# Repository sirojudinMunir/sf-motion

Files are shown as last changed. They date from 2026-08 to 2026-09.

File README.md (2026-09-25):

# SF-Motion

**Open-source BLDC/PMSM motor control platform based on STM32 and Field-Oriented Control (FOC).**

The project includes:

- FOC firmware
- Custom motor driver hardware
- KiCad schematic and PCB design
- Gerber and BOM files
- Python communication and control tools
- PyQt/PyQtGraph GUI for motor monitoring and testing

> ⚠️ This project is under active development. Hardware and firmware may change between versions.

## Hardware Prerequisites

You will need:
- FOC Driver Board
- ST-Link programmer/debugger with 3-pin Molex pico-blade P1.25mm connector
- DC power supply
- BLDC/PMSM motor
- diametrical magnet
- USB type-C cable
- power cable with XT-30 female connector

The hardware design is available in:
```
Hardware/
├── production/        # Gerber manufacturing files
├── .kicad_sch         # Schematic
├── .kicad_pcb         # PCB design
└── ...
```

## Software Prerequisites

### 1. STM32CubeMX

Used to configure the STM32 peripherals and generate the initial project configuration.

Download: https://www.st.com/en/development-tools/stm32cubemx.html

### 2. Visual Studio Code

Used as the main development environment.

Download: https://code.visualstudio.com/

### 3. PlatformIO

PlatformIO is used to build and upload the firmware.

Install PlatformIO through the VS Code extension:
1. Open VS Code.
2. Open Extensions.
3. Search for PlatformIO IDE.
4. Install the extension.
5. Restart VS Code if required.

Verify the installation:
``` bash
pio --version
```

If `pio` is not recognized in the terminal, use the PlatformIO terminal inside VS Code or add the PlatformIO CLI directory to your system PATH.

### 4. Python

Python is required for the communication tools and GUI.

Recommended version:
```text
Python 3.10+
```

Download: https://www.python.org/downloads/

Check the installation:
``` bash
python --version
```

Create a virtual environment (recommended):
``` bash
python -m venv .venv
```

Activate it on Windows:
``` bash
.venv\Scripts\activate
```

Activate it on Linux/macOS:
``` bash
source .venv/bin/activate
```

Install the required packages:
``` bash
pip install numpy pyserial PyQt5 pyqtgraph
```

## Getting Started

Clone the repository using Git:
``` bash
git clone https://github.com/sirojudinMunir/sf-motion.git
```

Enter the project directory:
``` bash
cd SF-Motion
```

## Building the Firmware

Open the project in VS Code with PlatformIO installed.

Build the firmware:
``` bash
pio run
```

If the build is successful, the firmware binary will be generated by PlatformIO.

## Upload Firmware

Connect the ST-Link to the FOC Driver board using the 3-pin PicoBlade connector.

The board can be powered from a **6–24 V external power supply**. For the initial test, it is recommended to use **USB Type-C** as the power source if applicable.

Upload the firmware:
``` bash
pio run -t upload
```

You can also use the Upload button in the PlatformIO interface in VS Code.

## For the first test

After uploading the firmware, follow these steps:

1. Make sure the D3 LED is blinking after the firmware starts.
2. Connect the BLDC/PMSM motor wires to the FOC Driver board. Make sure the diametrical magnet is securely mounted on the motor shaft and properly aligned with the magnetic encoder on the FOC Driver board. The board should be positioned directly beneath the magnet.
3. If you are using an external power supply, set the current limit to 1 A for the initial test. This helps prevent damage if there is an unexpected issue with the board or motor.
4. Connect the USB Type-C cable to the board.
5. Run the Python motor control program:
    ```python
    python communication/motor.py
    ```
6. Select the correct COM port and click Connect.

7. Before running the motor, set the correct motor pole pairs:
    ``` python
    motor.set_pole_pairs(<your_motor_pole_pairs>)
    ```
    Replace <your_motor_pole_pairs> with the actual number of pole pairs of your motor.
8. Run the self-commissioning process:
    ``` python
    motor.self_commissioning()
    ```
    The self-commissioning process measures the motor resistance and inductance and calibrates the magnetic encoder.
    >Important: During encoder calibration, make sure the motor rotates counter-clockwise (CCW). If the motor rotates in the opposite direction, swap any two motor wires to reverse the rotation.
    Automatic motor direction detection will be implemented in a future version.
9. Save configuration
    ``` python
    motor.set_save_config()
    ```
10. Test the FOC motor modes using:
    ``` python
    motor.set_motor_mode(<mode>)
    ```
    Available modes:

    0 -> for current control mode  
    1 -> for speed control mode  
    2 -> for position control mode  
    5 -> for open-loop mode  
    6 -> for disable the motor

> ⚠️ Keep the power supply current limit low during the first test. Do not increase the voltage or current limit until the board, encoder, and motor are confirmed to be working correctly.

---

## Support SF-Motion

If you find this project useful and would like to support its development,
you can become a sponsor:



Your support helps fund hardware development, testing, documentation,
and future improvements to SF-Motion.

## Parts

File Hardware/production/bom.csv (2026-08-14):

Designator | Footprint | Quantity | Value | LCSC Part #
C1, C10, C11, C2, C21, C3, C31, C37, C4, C40, C41, C45, C47, C48, C49, C5, C50, C51, C7 | 0402 | 19 | 100nF | C1525
C12, C16, C17, C25, C26, C27, C28, C29, C30, C32, C33, C34, C35, C38, C39, C43, C44 | 0805 | 17 | 10uF | C22367830
C13, C15 | 0603 | 2 | 0.1uF | C1591
C14 | 0805 | 1 | 4.7uF | C98192
C18, C20, C22 | 0603 | 3 | 1uF | C5199872
C19 | 0603 | 1 | 47nF | C1622
C23 | 0603 | 1 | 2.2uF | C23630
C24 | 0402 | 1 | 10nF | C15195
C36, C42, C46 | 0402 | 3 | 1nF | C14442
C6 | 0402 | 1 | 1uF | C29266
C8, C9 | 0402 | 2 | 33pF | C70465
D1, D2 | 0603 | 2 | LED RED | C19171390
D3 | 0603 | 1 | LED GREEN | C2986048
D4, D5 | D_SOD-123 | 2 | MBR0530 | C5204746
FB1 | 0603 | 1 | fcm 1608-0603 | C19330
J1, J8, J9 | Molex_PicoBlade_53261-0371_1x03-1MP_P1.25mm_Horizontal | 3 | Conn_01x03_MountingPin | C293630
J10 | Molex_PicoBlade_53261-0671_1x06-1MP_P1.25mm_Horizontal | 1 | Conn_01x06_MountingPin | C17393620
J11 | Molex_PicoBlade_53261-0571_1x05-1MP_P1.25mm_Horizontal | 1 | Conn_01x05_MountingPin | C17256390
J2, J3 | AMASS_XT30PW-M_1x02_P2.50mm_Horizontal | 2 | Conn_01x02 | C431092
J4, J5, J6 | SolderWire-0.25sqmm_1x01_D0.65mm_OD2mm | 3 | Conn_01x01
J7 | USB_C_Receptacle_G-Switch_GT-USB-7010ASV | 1 | USB_C_Receptacle_USB2.0_16P | C2927039
L1 | L_SMD_4X4 | 1 | 22uH | C6364792
Q1, Q2, Q3, Q4, Q5, Q6 | TDSON-8-1 | 6 | WSD30100DN56 | C2862136
R1, R3 | 0402 | 2 | 10k | C60490
R10, R11, R7, R8 | 0402 | 4 | R
R12, R15, R17, R21, R22, R25 | 0603 | 6 | 10R | C844919
R13, R19, R23 | R_Shunt_Ohmite_LVK20 | 3 | 0.01R | C844898
R14, R2, R20, R24, R32, R33, R34, R4, R5 | 0402 | 9 | 1k | C852624
R16 | 0603 | 1 | 39k | C163424
R18 | 0603 | 1 | 2k2 | C125931
R26 | 0402 | 1 | 1k8 | C163481
R27, R28 | 0402 | 2 | 100R | C705627
R29, R31 | 0402 | 2 | 30R | C852718
R30 | 0603 | 1 | 120R | C125925
R35, R36, R37 | 0402 | 3 | 2k | C852711
R6 | 0603 | 1 | 18k | C309650
R9 | 0603 | 1 | 3k3 | C144661
TP1, TP2, TP3, TP4, TP5, TP6, TP7 | TestPoint_Pad_D1.0mm | 7 | TestPoint
U1 | LQFP-64_10x10mm_P0.5mm | 1 | STM32F405RGTx | C15742
U10 | TSSOP-14_4.4x5mm_P0.65mm | 1 | AS5047D | C2693743
U2 | QFN50P700X700X100-49N | 1 | DRV8323RHRGZR | C543035
U3 | SOT-23-5 | 1 | LP2985-3.3 | C95414
U4, U6, U7 | TSSOP-8_4.4x3mm_P0.65mm | 3 | INA240A1PW | C93965
U5 | SOT-23-5 | 1 | LM321 | C5252901
U8 | SOT-23-6 | 1 | USBLC6-2SC6 | C2827654
U9 | HVSON-8-1EP_3x3mm_P0.65mm_EP1.6x2.4mm | 1 | TJA1051TK-3 | C2875699
Y1 | Crystal_SMD_3225-4Pin_3.2x2.5mm | 1 | 12MHz | C9002

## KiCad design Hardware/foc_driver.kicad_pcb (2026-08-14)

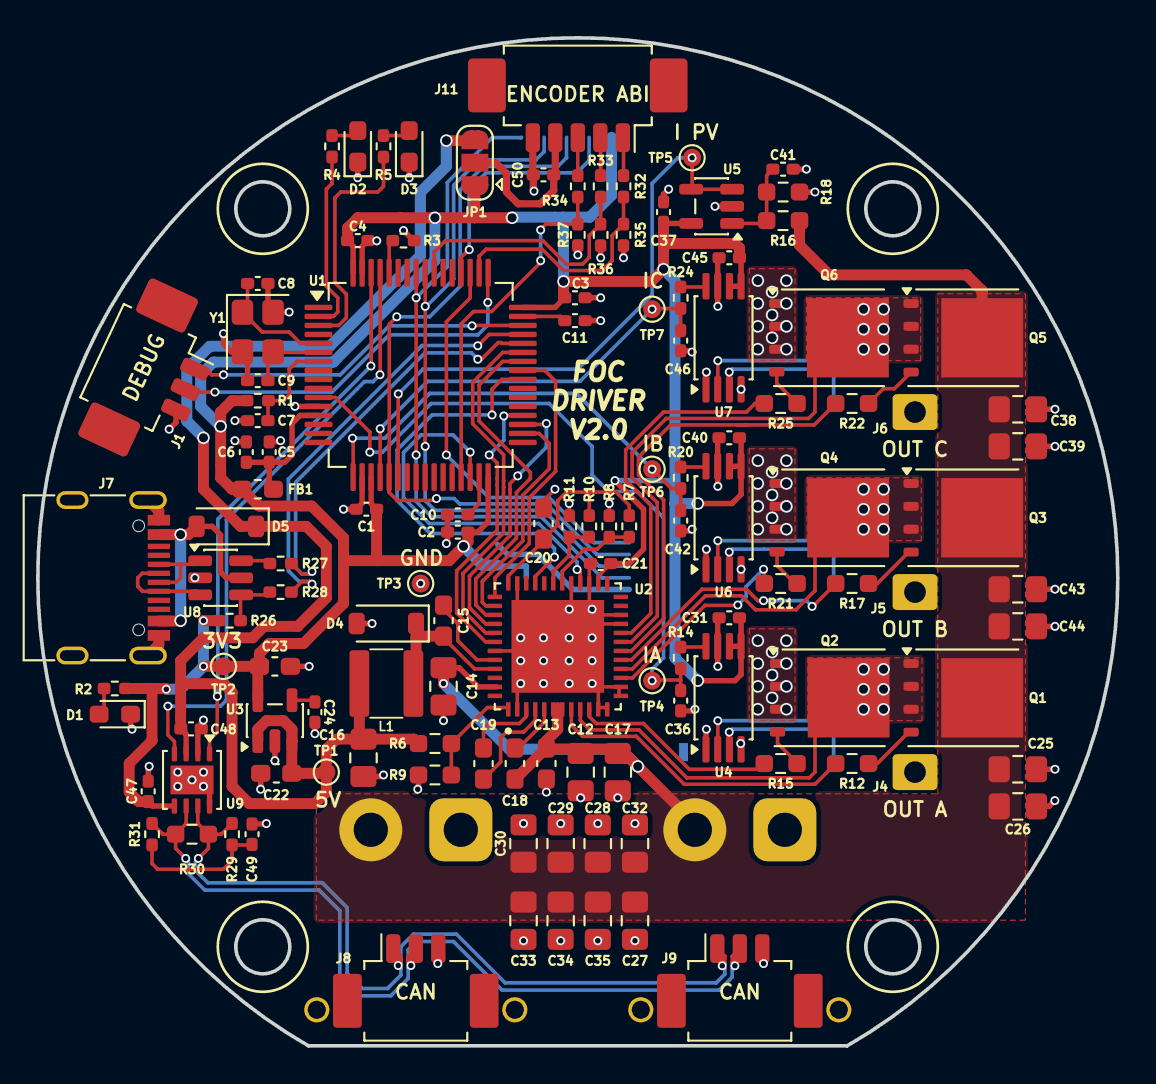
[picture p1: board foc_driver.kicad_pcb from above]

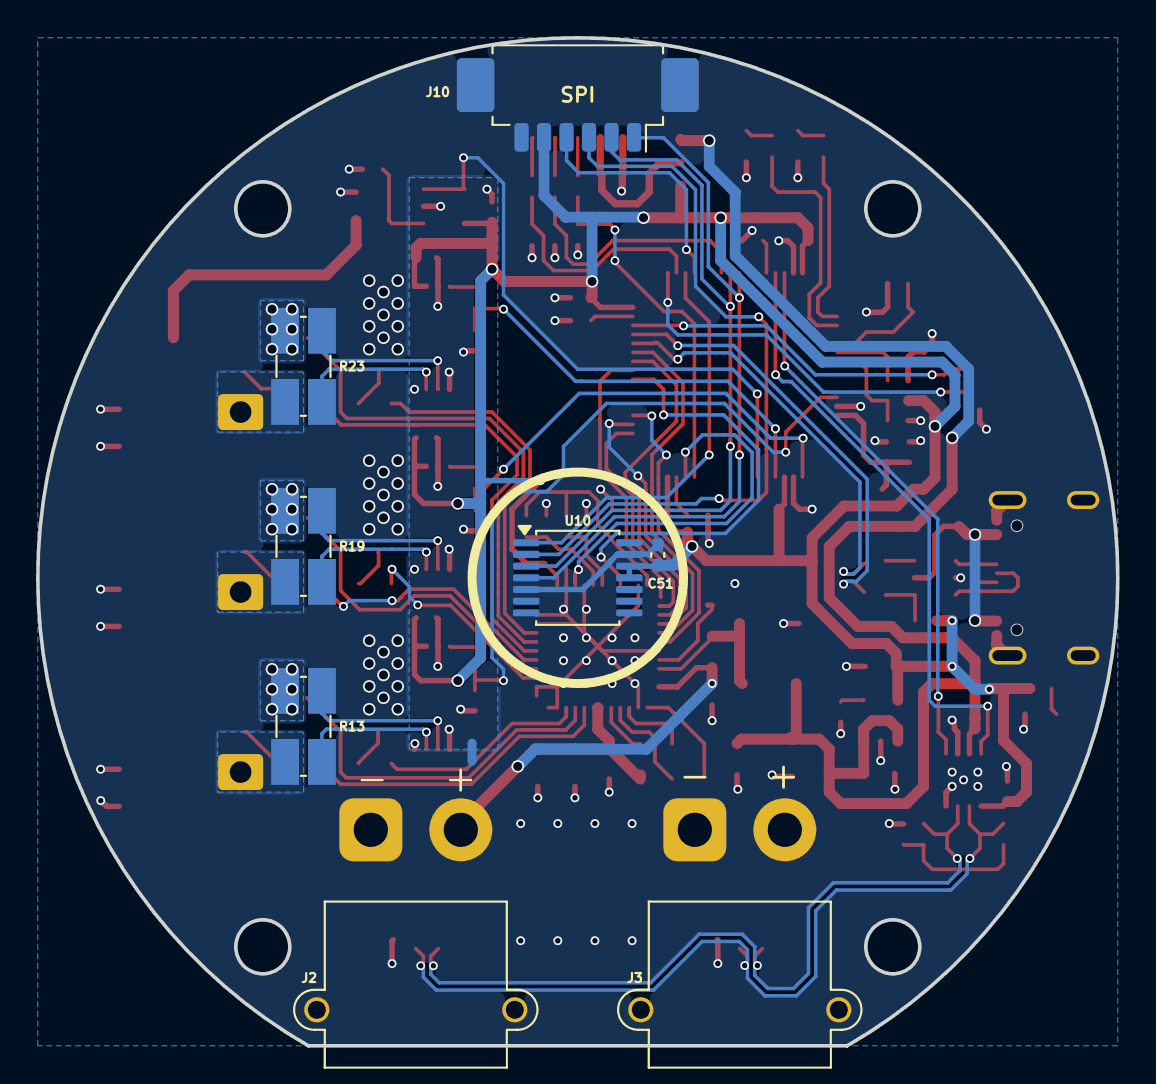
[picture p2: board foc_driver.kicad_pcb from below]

Board: 2 copper layers, 60.0 x 56.0 mm, 132 parts (9 on the bottom side), 93 nets.

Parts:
C1, C2, C3, C4, C5, C7, C10, C11, C21, C31, C37, C40, C41, C45, C47, C48, C49, C50, C51: 100nF; C_0402_1005Metric_Pad0.74x0.62mm_HandSolder
C6: 1uF; C_0402_1005Metric_Pad0.74x0.62mm_HandSolder
C8, C9: 33pF; C_0402_1005Metric_Pad0.74x0.62mm_HandSolder
C12, C16, C17, C25, C26, C27, C28, C29, C30, C32, C33, C34, C35, C38, C39, C43, C44: 10uF; C_0805_2012Metric_Pad1.18x1.45mm_HandSolder
C13, C15: 0.1uF; C_0603_1608Metric_Pad1.08x0.95mm_HandSolder
C14: 4.7uF; C_0805_2012Metric_Pad1.18x1.45mm_HandSolder
C18, C20, C22: 1uF; C_0603_1608Metric_Pad1.08x0.95mm_HandSolder
C19: 47nF; C_0603_1608Metric_Pad1.08x0.95mm_HandSolder
C23: 2.2uF; C_0603_1608Metric_Pad1.08x0.95mm_HandSolder
C24: 10nF; C_0402_1005Metric_Pad0.74x0.62mm_HandSolder
C36, C42, C46: 1nF; C_0402_1005Metric_Pad0.74x0.62mm_HandSolder
D1, D2: LED RED; LED_0603_1608Metric_Pad1.05x0.95mm_HandSolder
D3: LED GREEN; LED_0603_1608Metric_Pad1.05x0.95mm_HandSolder
D4, D5: MBR0530; D_SOD-123
FB1: fcm 1608-0603; L_0603_1608Metric_Pad1.05x0.95mm_HandSolder
J1, J8, J9: Conn_01x03_MountingPin; Molex_PicoBlade_53261-0371_1x03-1MP_P1.25mm_Horizontal
J2, J3: Conn_01x02; AMASS_XT30PW-M_1x02_P2.50mm_Horizontal
J4, J5, J6: Conn_01x01; SolderWire-0.25sqmm_1x01_D0.65mm_OD2mm
J7: USB_C_Receptacle_USB2.0_16P; USB_C_Receptacle_G-Switch_GT-USB-7010ASV
J10: Conn_01x06_MountingPin; Molex_PicoBlade_53261-0671_1x06-1MP_P1.25mm_Horizontal
J11: Conn_01x05_MountingPin; Molex_PicoBlade_53261-0571_1x05-1MP_P1.25mm_Horizontal
JP1: SolderJumper_3_Open; SolderJumper-3_P1.3mm_Open_RoundedPad1.0x1.5mm
L1: 22uH; L_SMD_4X4
NT1: NetTie_2; NetTie-2_SMD_Pad0.5mm
Q1, Q2, Q3, Q4, Q5, Q6: WSD30100DN56; TDSON-8-1
R1, R3: 10k; R_0402_1005Metric_Pad0.72x0.64mm_HandSolder
R2, R4, R5, R14, R20, R24, R32, R33, R34: 1k; R_0402_1005Metric_Pad0.72x0.64mm_HandSolder
R6: 18k; R_0603_1608Metric_Pad0.98x0.95mm_HandSolder
R7, R8, R10, R11: R; R_0402_1005Metric_Pad0.72x0.64mm_HandSolder
R9: 3k3; R_0603_1608Metric_Pad0.98x0.95mm_HandSolder
R12, R15, R17, R21, R22, R25: 10R; R_0603_1608Metric_Pad0.98x0.95mm_HandSolder
R13, R19, R23: 0.01R; R_Shunt_Ohmite_LVK20
R16: 39k; R_0603_1608Metric_Pad0.98x0.95mm_HandSolder
R18: 2k2; R_0603_1608Metric_Pad0.98x0.95mm_HandSolder
R26: 1k8; R_0402_1005Metric_Pad0.72x0.64mm_HandSolder
R27, R28: 100R; R_0402_1005Metric_Pad0.72x0.64mm_HandSolder
R29, R31: 30R; R_0402_1005Metric_Pad0.72x0.64mm_HandSolder
R30: 120R; R_0603_1608Metric_Pad0.98x0.95mm_HandSolder
R35, R36, R37: 2k; R_0402_1005Metric_Pad0.72x0.64mm_HandSolder
TP1, TP2, TP3, TP4, TP5, TP6, TP7: TestPoint; TestPoint_Pad_D1.0mm
U1: STM32F405RGTx; LQFP-64_10x10mm_P0.5mm
U2: DRV8323RHRGZR; QFN50P700X700X100-49N
U3: LP2985-3.3; SOT-23-5
U4, U6, U7: INA240A1PW; TSSOP-8_4.4x3mm_P0.65mm
U5: LM321; SOT-23-5
U8: USBLC6-2SC6; SOT-23-6
U9: TJA1051TK-3; HVSON-8-1EP_3x3mm_P0.65mm_EP1.6x2.4mm
U10: AS5047D; TSSOP-14_4.4x5mm_P0.65mm
Y1: 12MHz; Crystal_SMD_3225-4Pin_3.2x2.5mm

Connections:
+3V3: C1.1, C2.1, C3.1, C4.1, C21.2, C23.1, C31.1, C37.1, C40.1, C45.1, C47.2, C51.1, FB1.2, J10.5, JP1.1 (A), R1.1, R2.1, R26.1, TP2.1 (1_1), U1.19 (VDD), U1.32 (VDD), U1.48 (VDD), U1.64 (VDD), U2.26 (VREF), U3.5 (VOUT), U4.5 (V+), U4.6 (REF2), U5.5 (V+), U6.5 (V+), U6.6 (REF2), U7.5 (V+), U7.6 (REF2), U9.5 (VIO), U10.11 (VDD), U10.12 (VDD3V3)
+3V3A: C5.1, C6.1, FB1.1, U1.13 (VDDA)
+5V: C16.1, C22.1, C48.2, D5.1 (K), JP1.3 (B), L1.2, R6.1, TP1.1 (1_1), U3.1 (VIN), U3.3 (ON/~OFF), U9.3 (VCC)
/Communications/CAN_N: J8.2, J9.2, R30.2, R31.2, U9.6 (CANL)
/Communications/CAN_P: J8.1, J9.1, R29.2, R30.1, U9.7 (CANH)
/Communications/CAN_RX: U1.61 (PB8), U9.4 (RXD)
/Communications/CAN_TX: U1.62 (PB9), U9.1 (TXD)
/Communications/USB_N: R27.2, U1.44 (PA11)
/Communications/USB_P: R28.2, U1.45 (PA12)
/Communications/VBUS: D5.2 (A), J7.A4 (VBUS), J7.A9 (VBUS), J7.B4 (VBUS), J7.B9 (VBUS), U8.5 (VBUS)
/Encoders/CS0: U1.51 (PC10), U10.1 (~CS)
/Encoders/CS1: J10.4, U1.52 (PC11)
/Encoders/EXT_ENCDA: R32.1, R35.1, U1.50 (PA15)
/Encoders/EXT_ENCDB: R33.1, R36.1, U1.55 (PB3)
/Encoders/EXT_ENCDI: R34.1, R37.1, U1.29 (PB10)
/Encoders/MISO: J10.2, U1.56 (PB4), U10.3 (MISO)
/Encoders/MOSI: J10.1, U1.57 (PB5), U10.4 (MOSI)
/Encoders/SCK: J10.3, U1.21 (PA5), U10.2 (CLK)
/Gate Driver/EN_GATE: U1.40 (PC9), U2.33 (ENABLE)
/Gate Driver/FAULT: U1.30 (PB11), U2.28 (NFAULT)
/Gate Driver/GHA: R12.1, U2.8 (GHA)
/Gate Driver/GHB: R17.1, U2.17 (GHB)
/Gate Driver/GHC: R22.1, U2.18 (GHC)
/Gate Driver/GLA: R15.1, U2.10 (GLA)
/Gate Driver/GLB: R21.1, U2.15 (GLB)
/Gate Driver/GLC: R25.1, U2.20 (GLC)
/Gate Driver/IDRIVE: R7.2, R8.2, U2.30 (IDRIVE)
/Gate Driver/INH_A: U1.41 (PA8), U2.37 (INHA)
/Gate Driver/INH_B: U1.42 (PA9), U2.39 (INHB)
/Gate Driver/INH_C: U1.43 (PA10), U2.41 (INHC)
/Gate Driver/INL_A: U1.34 (PB13), U2.38 (INLA)
/Gate Driver/INL_B: U1.35 (PB14), U2.40 (INLB)
/Gate Driver/INL_C: U1.36 (PB15), U2.42 (INLC)
/Gate Driver/SHA: Q1.1 (S), Q1.2 (S), Q1.3 (S), Q2.5 (D), R13.1, U2.9 (SHA)
/Gate Driver/SHB: Q3.1 (S), Q3.2 (S), Q3.3 (S), Q4.5 (D), R19.1, U2.16 (SHB)
/Gate Driver/SHC: Q5.1 (S), Q5.2 (S), Q5.3 (S), Q6.5 (D), R23.1, U2.19 (SHC)
/Gate Driver/VDS: R10.2, R11.2, U2.31 (VDS)
/Inverter/ISENSE_A: C36.1, R14.2, TP4.1 (1_1), U1.11 (PC3)
/Inverter/ISENSE_B: C42.1, R20.2, TP6.1 (1_1), U1.17 (PA3)
/Inverter/ISENSE_C: C46.1, R24.2, TP7.1 (1_1), U1.20 (PA4)
/Inverter/OUT_A: J4.1 (Pin_1_1), R13.4
/Inverter/OUT_B: J5.1 (Pin_1_1), R19.4
/Inverter/OUT_C: J6.1 (Pin_1_1), R23.4
/Inverter/PV_SENSE: TP5.1 (1_1), U1.22 (PA6), U5.3 (-), U5.4
/MCU/BOOT0: R3.2, U1.60 (BOOT0)
/MCU/LED_G: R5.1, U1.3 (PC14)
/MCU/LED_R: R4.1, U1.2 (PC13)
/MCU/NRST: C7.1, R1.2, U1.7 (NRST)
/MCU/OSC_IN: C8.2, U1.5 (PH0), Y1.1
/MCU/OSC_OUT: C9.2, U1.6 (PH1), Y1.3
/MCU/SWCLK: J1.2, U1.49 (PA14)
/MCU/SWDIO: J1.1, U1.46 (PA13)
DVDD: C20.1, R7.1, R10.1, U2.36 (DVDD)
GND: C1.2, C2.2, C3.2, C4.2, C5.2, C6.2, C7.2, C8.1, C9.1, C10.2, C11.2, C12.2, C13.2, C14.2, C16.2, C17.2, C20.2, C21.1, C22.2, C23.2, C24.2, C25.1, C26.1, C27.1, C28.1, C29.1, C30.1, C32.1, C33.1, C34.1, C35.1, C38.1, C39.1, C41.2, C43.1, C44.1, C47.1, C48.1, C49.1, C50.1, C51.2, D1.1 (K), D2.1 (K), D3.1 (K), D4.2 (A), J1.3, J2.1, J3.1, J7.A1 (GND), J7.A12 (GND), J7.B1 (GND), J7.B12 (GND), J7.S1 (SHIELD), J8.3, J9.3, J10.6, J11.5, NT1.2, Q2.1 (S), Q2.2 (S), Q2.3 (S), Q4.1 (S), Q4.2 (S), Q4.3 (S), Q6.1 (S), Q6.2 (S), Q6.3 (S), R3.1, R8.1, R9.2, R11.1, R18.2, R35.2, R36.2, R37.2, TP3.1 (1_1), U1.12 (VSSA), U1.18 (VSS), U1.63 (VSS), U2.2 (PGND), U2.11 (SPA), U2.12 (SNA), U2.13 (SNB), U2.14 (SPB), U2.21 (SPC), U2.22 (SNC), U2.27 (DGND), U2.29 (MODE), U2.35 (AGND), U2.43 (BGND), U2.49 (EP), U3.2 (GND), U8.2 (GND), U9.2 (GND), U9.8 (S), U9.9 (GND), U10.5 (TST), U10.13 (GND), Y1.2 (G), Y1.4 (G)
GNDA: C31.2, C36.2, C37.2, C40.2, C42.2, C45.2, C46.2, NT1.1, U4.1 (GND), U4.4 (GND), U4.7 (REF1), U5.2 (V-), U6.1 (GND), U6.4 (GND), U6.7 (REF1), U7.1 (GND), U7.4 (GND), U7.7 (REF1)
unnamed: C49.2, R29.1, R31.1
unnamed: D1.2 (A), R2.2
unnamed: D2.2 (A), R4.2
unnamed: D3.2 (A), R5.2
unnamed: C15.2, D4.1 (K), L1.1, U2.45 (SW)
unnamed: J7.A6 (D+), J7.B6 (D+), U8.3 (I/O2)
unnamed: J7.A7 (D-), J7.B7 (D-), U8.1 (I/O1)
unnamed: J11.1, R32.2
unnamed: J11.2, R33.2
unnamed: J11.3, R34.2
unnamed: C50.2, J11.4, JP1.2 (C)
unnamed: Q1.4 (G), R12.2
unnamed: Q2.4 (G), R15.2
unnamed: Q3.4 (G), R17.2
unnamed: Q4.4 (G), R21.2
unnamed: Q5.4 (G), R22.2
unnamed: Q6.4 (G), R25.2
unnamed: R14.1, U4.8
unnamed: R20.1, U6.8
unnamed: R24.1, U7.8
unnamed: R26.2, R28.1, U8.4 (I/O2)
unnamed: R27.1, U8.6 (I/O1)
unnamed: C10.1, U1.31 (VCAP_1)
unnamed: C11.1, U1.47 (VCAP_2)
unnamed: C15.1, U2.44 (CB)
unnamed: C19.2, U2.4 (CPH)
unnamed: C19.1, U2.3 (CPL)
unnamed: R6.2, R9.1, U2.1 (FB)
unnamed: C18.1, U2.5 (VCP)
unnamed: C24.1, U3.4 (BP)
unnamed: R13.2, U4.2 (+)
unnamed: R13.3, U4.3 (-)
unnamed: C41.1, R16.2, R18.1, U5.1 (+)
unnamed: R19.2, U6.2 (+)
unnamed: R19.3, U6.3 (-)
unnamed: R23.2, U7.2 (+)
unnamed: R23.3, U7.3 (-)
VS: C12.1, C13.1, C14.1, C17.1, C18.2, C25.2, C26.2, C27.2, C28.2, C29.2, C30.2, C32.2, C33.2, C34.2, C35.2, C38.2, C39.2, C43.2, C44.2, J2.2, J3.2, Q1.5 (D), Q3.5 (D), Q5.5 (D), R16.1, U2.6 (VM), U2.7 (VDRAIN), U2.47 (VIN)

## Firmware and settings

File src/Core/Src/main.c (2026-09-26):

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
/* Includes ------------------------------------------------------------------*/
#include "main.h"
#include "usb_device.h"

/* USER CODE BEGIN Includes */
#include "device_config.h"
#include "stm32f405_link.h"
#include "motor.h"
#include "AS5047P.h"
#include "FOC_utils.h"
#include "self_commissioning.h"
#include "storage.h"
#include "sf_motion_usb_com.h"
#include "sf_motion_com.h"
#include "string.h"
/* USER CODE END Includes */

/* USER CODE BEGIN PD */

#define usb_print(fmt, ...)                                                 \
  do {                                                                      \
    snprintf(usb_send_buff, sizeof(usb_send_buff), fmt, ##__VA_ARGS__);     \
    CDC_Transmit_FS((uint8_t *)(usb_send_buff), sizeof(usb_send_buff) - 1); \
  } while (0)

/* USER CODE END PD */

/* USER CODE BEGIN PM */
extern uint8_t CDC_Transmit_FS(uint8_t* Buf, uint16_t Len);
/* USER CODE END PM */

ADC_HandleTypeDef hadc1;

CAN_HandleTypeDef hcan1;

SPI_HandleTypeDef hspi1;
DMA_HandleTypeDef hdma_spi1_tx;
DMA_HandleTypeDef hdma_spi1_rx;

TIM_HandleTypeDef htim1;

/* USER CODE BEGIN PV */

AS5047P_t hencd1;
uint32_t adc_buff[4];
foc_t hfoc1;
self_commissioning_t hsc1;
storage_t hstorage1;

sfm_usb_com_t hsfm_usb_com;
sfm_com_t husb_com;
sfm_com_t hcan_com;

char usb_send_buff[64];
uint8_t can_send_buff[64];
uint8_t can_recv_buff[64];

/* USER CODE END PV */

void SystemClock_Config(void);
static void MX_GPIO_Init(void);
static void MX_DMA_Init(void);
static void MX_TIM1_Init(void);
static void MX_ADC1_Init(void);
static void MX_SPI1_Init(void);
static void MX_CAN1_Init(void);
/* USER CODE BEGIN 0 */

/**************************************************************************** */
// implementation

void motor1_inverter_enable(void) {
  EN_GATE1_GPIO_Port->BSRR = EN_GATE1_Pin;
  link_enable_pwm(&htim1);
  link_enable_adc(&hadc1);
}

void motor1_inverter_disable(void) {
  EN_GATE1_GPIO_Port->BSRR = EN_GATE1_Pin<<16;
  link_disable_pwm(&htim1);
  link_disable_adc(&hadc1);
}

uint32_t motor1_get_pwm_res(void) {
  return link_get_max_pwm(&htim1);
}

float motor1_as5047p_get_mech_deg(void) {
  return AS5047P_get_degree(&hencd1);
}

int motor1_as5047p_spi_transmit(uint8_t *tx, uint8_t *rx, uint16_t len) {
  if (HAL_SPI_TransmitReceive_DMA(&hspi1, tx, rx, len) == HAL_OK) return 0;
  return -1;
}

void motor1_as5047p_spi_cs(_Bool cs_state) {
  if (cs_state) SPI_CS_GPIO_Port->BSRR = SPI_CS_Pin;
  else SPI_CS_GPIO_Port->BSRR = SPI_CS_Pin<<16;
}

int write_flash(void *data, uint32_t len) {
  return link_write_flash(data, len);
}

int read_flash(void *data, uint32_t len) {
  memcpy(data, (void*)FLASH_SECTOR_ADDR, len);
  return 0;
}

int usb_send_data(uint8_t *data, uint16_t len) {
  if (CDC_Transmit_FS(data, len) != USBD_OK) return -1;
  return 0;
}

int sfm_com_usb_send_data(uint8_t *data, uint16_t len) {
  if (sfm_usb_com_start_send_data(&hsfm_usb_com, data, len) == 0) return 0;
  return -1;
}

int sfm_com_usb_recv_data(uint8_t *data, uint16_t len) {
  (void)data;
  (void)len;
  return 0;
}

int can_recv_data(uint8_t *data, uint16_t len) {
  (void)data;
  (void)len;
  return 0;
}

int can_send_data(uint8_t *data, uint16_t len) {
  uint32_t can_std_id = (data[0] << 8) | data[1];
  return link_can_send_data(can_std_id, data + 2, len);
}

/**************************************************************************** */

static void init_motor(void) {
  motor_init_pwm(&hfoc1.motor, &TIM1->CCR1, &TIM1->CCR2, &TIM1->CCR3);
  motor_init_adc_current_sense(&hfoc1.motor, &adc_buff[0], &adc_buff[1], &adc_buff[2]);
  motor_init_adc_power_voltage_sense(&hfoc1.motor, &adc_buff[3]);
  motor_set_current_sense_gain(&hfoc1.motor, (3.3f / 4095.0f) / (0.01f * 20.0f));
  motor_set_power_voltage_sense_gain(&hfoc1.motor, (3.3f / 4095.0f)*((39.0f + 2.2f) / 2.2f));
  motor_init_lpf_power_voltage_sense(&hfoc1.motor, 100, BLDC_PWM_FREQ);
  CSA_CAL1_GPIO_Port->BSRR = CSA_CAL1_Pin << 16;
}

static void init_encoder(void) {
  AS5047P_spi_config(&hencd1, motor1_as5047p_spi_transmit, motor1_as5047p_spi_cs);
  AS5047P_init(&hencd1, SENSOR_DIR_REVERSE, (360.0f / 16383.0f));
  AS5047P_set_angle_filter_fc(&hencd1, 1000.0f, FOC_TS);
  AS5047P_set_rpm_filter_fc(&hencd1, 50.0f, FOC_TS);
}

static void init_foc(void) {
#if USB_TO_CAN
  link_can_init(USB_TO_CAN_DEVICE_ID);
  sfm_usb_com_init(&hsfm_usb_com, usb_send_data);
  sfm_com_init(&husb_com, sfm_com_usb_recv_data, sfm_com_usb_send_data, HAL_GetTick, &hfoc1, &hstorage1, &hsc1);
  sfm_com_init(&hcan_com, can_recv_data, can_send_data, HAL_GetTick, &hfoc1, &hstorage1, &hsc1);
#else
  storage_init(&hstorage1, write_flash, read_flash);
  storage_read_config(&hstorage1);
  storage_copy_to_local(&hstorage1, &hfoc1);

  init_trig_lut();
  link_set_pwm_freq(&htim1, BLDC_PWM_FREQ);
  init_motor();
  init_encoder();
  sc_init(&hsc1, &hfoc1);

  foc_inverter_init(&hfoc1, motor1_inverter_enable, motor1_inverter_disable, motor1_get_pwm_res);
  foc_feedback_sensor_init(&hfoc1, motor1_as5047p_get_mech_deg, hstorage1.memory.encoder_config.error_comp_deg, NORMAL_DIR);
  foc_speed_feedback_sensor_init(&hfoc1, 500.0f, 1.0f/SPEED_TS);

  link_can_init(hfoc1.motor.device_id);
  sfm_usb_com_init(&hsfm_usb_com, usb_send_data);
  sfm_com_init(&husb_com, sfm_com_usb_recv_data, sfm_com_usb_send_data, HAL_GetTick, &hfoc1, &hstorage1, &hsc1);
  sfm_com_init(&hcan_com, can_recv_data, can_send_data, HAL_GetTick, &hfoc1, &hstorage1, &hsc1);

  // Id PI parameter
  pid_reset(&hfoc1.id_ctrl);
  pid_set_ts(&hfoc1.id_ctrl, FOC_TS);
  // Id PI parameter
  pid_reset(&hfoc1.iq_ctrl);
  pid_set_ts(&hfoc1.iq_ctrl, FOC_TS);
  // Speed PID parameter
  pid_reset(&hfoc1.speed_ctrl);
  pid_set_ts(&hfoc1.speed_ctrl, SPEED_TS);
  pid_set_kd(&hfoc1.speed_ctrl, 0);
  pid_set_d_filter_fc(&hfoc1.speed_ctrl, 100.0f);
  pid_set_max_d(&hfoc1.speed_ctrl, 10.0f);
  // Position PID parameter
  pid_reset(&hfoc1.pos_ctrl);
  pid_set_ts(&hfoc1.pos_ctrl, POSITION_TS);
  pid_set_d_filter_fc(&hfoc1.pos_ctrl, 20.0f);
  pid_set_max_d(&hfoc1.pos_ctrl, 100.0f);
  // field weakening
  pid_reset(&hfoc1.fw_ctrl);
  pid_set_ts(&hfoc1.fw_ctrl, FOC_TS);

  // foc_motor_init(&hfoc1, hstorage1.memory.motor_config.pole_pairs, 360.0f);
  // foc_set_mode(&hfoc1, FOC_MODE_SENSORED);
  foc_sensorless_init(&hfoc1, BLDC_PWM_FREQ);

  foc_gear_reducer_init(&hfoc1, 1.0f);
  foc_set_limit_current(&hfoc1, 10.0f);
  
  foc_enable(&hfoc1);
#endif
}

static void indicator_update(void) {
  static uint32_t heartbeat_tick = 0;
  if (HAL_GetTick() - heartbeat_tick >= 500) {
    heartbeat_tick = HAL_GetTick();
    HAL_GPIO_TogglePin(LED_G_GPIO_Port, LED_G_Pin);
  }
  if (HAL_GPIO_ReadPin(NFAULT1_GPIO_Port, NFAULT1_Pin)) {
    LED_R_GPIO_Port->BSRR = LED_R_Pin<<16;
  }
  else {
    LED_R_GPIO_Port->BSRR = LED_R_Pin;
  }
}

static void self_commissioning_update(void) {
  if (sc_is_measure_done(&hsc1)) {
    switch(sc_get_seq(&hsc1)) {
      case SC_SEQUENCE_START_MEASURE_RS:
        foc_set_motor_Rs(&hfoc1, sc_get_Rs(&hsc1));
        break;
      case SC_SEQUENCE_START_MEASURE_LD:
        foc_set_motor_Ld(&hfoc1, sc_get_Ld(&hsc1));
        break;
      case SC_SEQUENCE_START_MEASURE_LQ:
        foc_set_motor_Lq(&hfoc1, sc_get_Lq(&hsc1));
        break;
      case SC_SEQUENCE_START_CALIBRATE_ABS_ENCODER:
        break;
    }
  }
}

void usb_to_can_update(void) {
  if (husb_com.incomming_data_flag) {
    husb_com.incomming_data_flag = 0;
    hcan_com.send_data(husb_com.data_rx, husb_com.data_rx_len);
  }
  if (hcan_com.incomming_data_flag) {
    hcan_com.incomming_data_flag = 0;
    husb_com.send_data(hcan_com.data_rx, hcan_com.data_rx_len);
  }
}

/**************************************************************************** */

void HAL_SPI_TxRxCpltCallback(SPI_HandleTypeDef *hspi) {
	if (hspi->Instance == SPI1) {
    AS5047P_set_spi_transfer_done(&hencd1);
	}
}

void HAL_ADCEx_InjectedConvCpltCallback(ADC_HandleTypeDef* hadc) {
	if (hadc->Instance == ADC1) {
    adc_buff[0] = ADC1->JDR1; // current sense A
    adc_buff[1] = ADC1->JDR2; // current sense B
    adc_buff[2] = ADC1->JDR3; // current sense C
    adc_buff[3] = ADC1->JDR4; // power voltage sense
    motor_calculate_power_voltage(&hfoc1.motor);
    motor_get_power_voltage(&hfoc1.motor, &hfoc1.v_bus);
    sc_update(&hsc1, FOC_TS);
    foc_update(&hfoc1, FOC_TS);
  }
}

// CAN RX FIFO 0 Callback
void HAL_CAN_RxFifo0MsgPendingCallback(CAN_HandleTypeDef *hcan){
  uint32_t id;
  if (link_can_recv_data(&id, hcan_com.data_rx, &hcan_com.data_rx_len) == 0) {
    hcan_com.incomming_data_flag = 1;
  }
}

/**************************************************************************** */

/* USER CODE END 0 */

/**
  * @brief  The application entry point.
  * @retval int
  */
int main(void)
{

  /* MCU Configuration--------------------------------------------------------*/

  /* Reset of all peripherals, Initializes the Flash interface and the Systick. */
  HAL_Init();

  /* Configure the system clock */
  SystemClock_Config();

  /* Initialize all configured peripherals */
  MX_GPIO_Init();
  MX_DMA_Init();
  MX_USB_DEVICE_Init();
  MX_TIM1_Init();
  MX_ADC1_Init();
  MX_SPI1_Init();
  MX_CAN1_Init();
  /* USER CODE BEGIN 2 */

#if (__FPU_PRESENT == 1) && (__FPU_USED == 1)
  printf("FPU aktif!\n");
#else
  printf("FPU tidak aktif!\n");
#endif

  init_foc();
  // uint32_t tick = HAL_GetTick();

  /* USER CODE END 2 */

  /* Infinite loop */
  /* USER CODE BEGIN WHILE */
  while (1)
  {
    indicator_update();
#if USB_TO_CAN
    usb_to_can_update();
#else
    AS5047P_update(&hencd1);
    sfm_com_update(&husb_com);
    sfm_com_update(&hcan_com);
    self_commissioning_update();
#endif
    /* USER CODE END WHILE */

    /* USER CODE BEGIN 3 */
  }
  /* USER CODE END 3 */
}

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


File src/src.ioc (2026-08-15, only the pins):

Mcu.UserName=STM32F405RGTx
PA10.Signal=S_TIM1_CH3
PA11.Signal=USB_OTG_FS_DM
PA12.Signal=USB_OTG_FS_DP
PA13.Signal=SYS_JTMS-SWDIO
PA14.Signal=SYS_JTCK-SWCLK
PA3.Signal=ADCx_IN3
PA4.Signal=ADCx_IN4
PA5.Signal=SPI1_SCK
PA6.Signal=ADCx_IN6
PA8.Signal=S_TIM1_CH1
PA9.Signal=S_TIM1_CH2
PB11.GPIO_Label=NFAULT1
PB11.Signal=GPIO_Input
PB13.Signal=TIM1_CH1N
PB14.Signal=TIM1_CH2N
PB15.Signal=TIM1_CH3N
PB4.Signal=SPI1_MISO
PB5.Signal=SPI1_MOSI
PB8.Signal=CAN1_RX
PB9.Signal=CAN1_TX
PC10.GPIO_Label=SPI_CS
PC10.Signal=GPIO_Output
PC13-ANTI_TAMP.GPIO_Label=LED_R
PC13-ANTI_TAMP.Signal=GPIO_Output
PC14-OSC32_IN.GPIO_Label=LED_G
PC14-OSC32_IN.Signal=GPIO_Output
PC3.Signal=ADCx_IN13
PC9.GPIO_Label=EN_GATE1
PC9.Signal=GPIO_Output
PH0-OSC_IN.Signal=RCC_OSC_IN
PH1-OSC_OUT.Signal=RCC_OSC_OUT

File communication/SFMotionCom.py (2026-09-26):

import struct
import serial
import time
import json
import numpy as np
from enum import IntEnum

class SFMComType(IntEnum):
    RESPONSE = 0x00
    READ = 0x01
    WRITE = 0x02
    ENABLE_STREAMING = 0x03
    DISABLE_STREAMING = 0x04
    STREAMING = 0x05
    EVENT = 0x06


class SFMotion:
    HEADER = b"\xA5\xA5"

    def __init__(self, serial_conn=None, acq_thread=None, node_id=1, json_path="SFMotionRegisters.json"):
        self.ser = serial_conn
        self.acq_thread = acq_thread
        self.node_id = node_id

        with open(json_path, "r") as f:
            config = json.load(f)

        self.registers = {
            item["address"]: item
            for item in config["registers"]
        }
        self.channel = IntEnum(
            "channel",
            {
                item["name"]: item["address"]
                for item in config["registers"]
                if item["streaming"]
            }
        )
        self._create_api()

    def _create_api(self):
        for register in self.registers.values():
            address = register["address"]
            name = register["name"]
            if register["read"]:
                setattr(self, f"get_{name}", 
                    lambda address=address: self.read(address)
                )
            if register["write"]:
                setattr(self, f"set_{name}",
                    lambda value=None, address=address: self.write(address, value)
                )

    def close(self):
        self.ser.close()

    # ------------------------------------------------------------
    # Low-level communication
    # ------------------------------------------------------------

    def _send_frame(self, com_type, address, data=b""):
        payload = bytes([com_type, self.node_id, address]) + data
        frame = (self.HEADER + bytes([len(payload)]) + payload)
        # print(f"TX: {frame.hex(' ')}")
        self.ser.write(frame)

    def read(self, address):
        register = self.registers.get(address)
        if register is None:
            raise ValueError(f"Unknown register address: {address}")
        if not register["read"]:
            raise ValueError(f"Address {address} ({register['name']}) is not readable")
        fmt = register["format"]
        if fmt is None:
            raise ValueError(f"Address {address} ({register['name']}) has no data format")
        size = struct.calcsize(fmt)
        self._send_frame(SFMComType.READ, address)
        response_node_id, response_address, data = (
            self.acq_thread.response_queue.get(timeout=2)
        )
        if response_node_id != self.node_id:
            raise RuntimeError(f"Unexpected node ID: {response_node_id}")
        if response_address != address:
            raise RuntimeError(f"Unexpected address: {response_address}")
        if len(data) != size:
            raise RuntimeError(f"Expected {size} bytes, received {len(data)}")
        return struct.unpack(fmt, data)[0]

    def write(self, address, value=None):
        register = self.registers.get(address)
        if register is None:
            raise ValueError(f"Unknown register address: {address}")
        if not register["write"]:
            raise ValueError(f"Address {address} ({register['name']}) is not writable")
        fmt = register["format"]
        if fmt is None:
            data = b""
        else:
            data = struct.pack(fmt, value)
        self._send_frame(SFMComType.WRITE, address, data,)
        response_node_id, response_address, response_data = (
            self.acq_thread.response_queue.get(timeout=2)
        )
        if response_node_id != self.node_id:
            raise RuntimeError(f"Unexpected node ID: {response_node_id}")
        if response_address != address:
            raise RuntimeError(f"Unexpected address: {response_address}")
        if len(response_data) != 1:
            raise RuntimeError(f"Invalid response length: {len(response_data)}")
        status = struct.unpack("<b", response_data)[0]
        if status != 0:
            raise RuntimeError(f"Device returned error: {status}")
        return True

    # ------------------------------------------------------------
    # Streaming
    # ------------------------------------------------------------

    def enable_streaming(self, address):
        self._send_frame(SFMComType.ENABLE_STREAMING, address,)
        response_node_id, response_address, response_data = self.acq_thread.response_queue.get(timeout=2)
        if response_node_id != self.node_id:
            raise RuntimeError(f"Unexpected node ID: {response_node_id}")
        if response_address != address:
            raise RuntimeError(f"Unexpected address: {response_address}")
        status = struct.unpack("<b", response_data)[0]
        if status != 0:
            raise RuntimeError(f"Device returned error: {status}")

    def disable_streaming(self, address):
        self._send_frame(SFMComType.DISABLE_STREAMING, address,)
        response_node_id, response_address, response_data = self.acq_thread.response_queue.get(timeout=2)
        if response_node_id != self.node_id:
            raise RuntimeError(f"Unexpected node ID: {response_node_id}")
        if response_address != address:
            raise RuntimeError(f"Unexpected address: {response_address}")
        status = struct.unpack("<b", response_data)[0]
        if status != 0:
            raise RuntimeError(f"Device returned error: {status}")

    # ----------------------------------------------------------------------------------
    
    def get_version(self):
        address = 1
        self._send_frame(SFMComType.READ, address)
        response_node_id, response_address, response_data = self.acq_thread.response_queue.get(timeout=2)
        if response_node_id != self.node_id:
            raise RuntimeError(f"Unexpected node ID: {response_node_id}")
        if response_address != address:
            raise RuntimeError(f"Unexpected address: {response_address}")
        major, minor, patch = struct.unpack("<3B", response_data)
        return major, minor, patch
    
    def self_commissioning(self):
        self.set_start_measure_resistance()
        time.sleep(1)
        self.set_start_measure_ld()
        time.sleep(1)
        self.set_start_measure_lq()
        time.sleep(1)
        self.get_motor_param()
        self.set_foc_bandwidth(500)
        self.set_start_calibrate_abs_encoder()
        self.set_pid_speed(0.005, 0.8, 10)
        self.set_pid_position(10, 0, 0, 1000)

    def get_motor_param(self):
        pole_pairs = self.get_pole_pairs()
        rs = self.get_rs()
        ld = self.get_ld()
        lq = self.get_lq()
        print(f'pole pairs:{pole_pairs}')
        print(f'Rs:{rs}')
        print(f'Ld:{ld}')
        print(f'Lq:{lq}')
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

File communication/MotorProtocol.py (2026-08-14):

import json
import struct
import time
import serial
import numpy as np

class MotorProtocol:
    def __init__(self, serial_conn=None, acq_thread=None, config_file='motor_commands.json'):
        self.ser = serial_conn
        self.acq_thread = acq_thread
        self.plotter_channels = []
        
        # Load config
        with open(config_file, 'r') as f:
            config = json.load(f)
            self.commands = config.get('commands', {})
            self.plotter_dict = config.get('plotter_dict', {})
        
        # Generate methods dynamically
        self._generate_methods()
    
    def _generate_methods(self):
        """Generate methods from JSON config"""
        for cmd_name, cmd_config in self.commands.items():
            setattr(self, cmd_name, self._create_method(cmd_name, cmd_config))
    
    def _create_method(self, cmd_name, cmd_config):
        """Create method for a specific command"""
        def method(*args, **kwargs):
            # Build data packet
            data = bytes([cmd_config['code']])
            
            # Process arguments
            arg_spec = cmd_config.get('args', [])
            
            # Handle both positional and keyword arguments
            all_args = list(args)
            for arg_info in arg_spec:
                arg_name = arg_info['name']
                if arg_name in kwargs:
                    all_args.append(kwargs[arg_name])
            
            if len(all_args) != len(arg_spec):
                raise ValueError(f"Expected {len(arg_spec)} args for {cmd_name}, got {len(all_args)}")

            # Plotter information
            plotter_item = None
            
            for i, arg_info in enumerate(arg_spec):
                arg_value = all_args[i]
                
                # Apply converter if specified
                if 'converter' in arg_info:
                    converter = arg_info['converter']
                    if converter == 'plotter_addr':
                        # Use the plotter_dict from JSON config
                        if isinstance(arg_value, str):
                            plotter_item = arg_value
                            try:
                                arg_value = self.plotter_dict[plotter_item]
                            except KeyError:
                                raise ValueError(f"Unknown plotter item: {arg_value}")
                            print(f"{plotter_item} = 0x{arg_value:04X}")
                        else:
                            arg_value = int(arg_value)
                    # Add more converters here as needed
                
                # Pack the argument based on type
                if arg_info['type'] == 'uint8':
                    data += bytes([arg_value])
                elif arg_info['type'] == 'float':
                    data += struct.pack('<f', arg_value)
                elif arg_info['type'] == 'uint16':
                    data += struct.pack('<H', arg_value)
                elif arg_info['type'] == 'int16':
                    data += struct.pack('<h', arg_value)
                elif arg_info['type'] == 'uint32':
                    data += struct.pack('<I', arg_value)
                elif arg_info['type'] == 'int32':
                    data += struct.pack('<i', arg_value)
                else:
                    raise ValueError(f"Unsupported argument type: {arg_info['type']}")
            
            # Send and receive
            response = cmd_config.get('response', [])
            ret = self.send_recv_data(data, response)
            cmd = cmd_config['code']
            # print(f'cmd: {cmd}')
            
            # plotter_add_line (code 7)
            if cmd == 7:
                if plotter_item is not None:
                    if plotter_item not in self.plotter_channels:
                        print(f'add plotter_item {plotter_item}')
                        self.plotter_channels.append(plotter_item)
            # plotter_remove_line (code 8)
            elif cmd == 8:
                if plotter_item is not None:
                    if plotter_item in self.plotter_channels:
                        print(f'remove plotter_item {plotter_item}')
                        self.plotter_channels.remove(plotter_item)
            return ret
        
        method.__name__ = cmd_name
        return method
    
    # ================================================================
    # Serial Connection

    def connect(self):
        self.ser = serial.Serial(
            self.port,
            self.baudrate,
            timeout=self.timeout
        )

    def reconnect(self):
        print("Reconnecting...")

        while True:
            try:
                if self.ser is not None:
                    if self.ser.is_open:
                        self.ser.close()

                time.sleep(1)

                self.ser = serial.Serial(
                    self.port,
                    self.baudrate,
                    timeout=self.timeout
                )

                print("Reconnected!")
                break

            except Exception:
                print(".", end="", flush=True)
                time.sleep(1)

    # ================================================================
    # Communication
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

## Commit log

2026-08-08 add kicad files
    [Communications.kicad_sch, Encoders.kicad_sch, Gate Driver.kicad_sch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]
2026-08-09 add firmware
    [Communications.kicad_sch, Encoders.kicad_sch, Gate Driver.kicad_sch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]
2026-08-13 use dynamic method based on json file
    [motor_commands.json]
2026-08-14 update BOM
    [Inverter.kicad_sch, bom.csv, foc_driver.kicad_pcb]
2026-08-14 add encoder callibration
    [motor_commands.json]
2026-08-15 add power voltage sense
    [motor_commands.json]
2026-08-15 reset speed_control_loop_count and position_control_loop_count
    [main.c]
2026-08-16 fix encoder error compensation
    [main.c]
2026-09-25 add: device ID, firmware version
2026-09-26 fix: mech angle calculation in sensored mode
    [SFMotionCom.py, main.c, plotter.py]
2026-11-05 add: auto calc pole pairs, auto set motor dir

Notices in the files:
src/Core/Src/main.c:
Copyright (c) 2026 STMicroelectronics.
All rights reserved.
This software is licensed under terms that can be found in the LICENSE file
